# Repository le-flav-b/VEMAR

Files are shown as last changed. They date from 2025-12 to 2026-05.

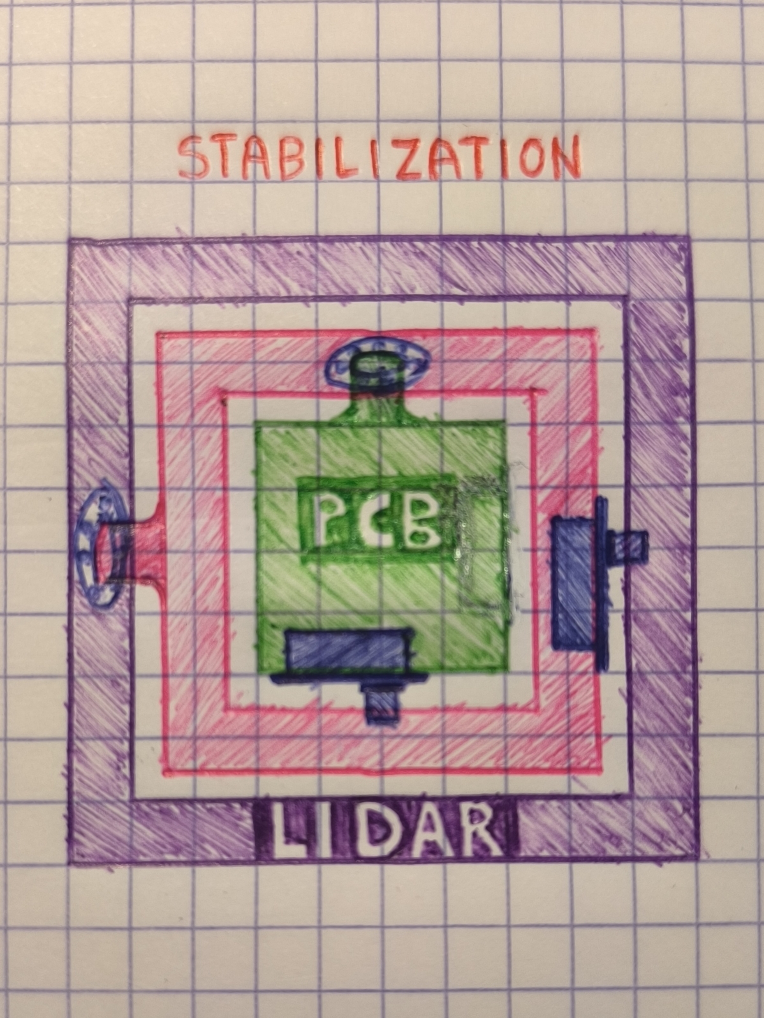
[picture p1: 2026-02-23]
mechanical/assets/lidar_schema_stabilization_concept.jpg

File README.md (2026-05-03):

Technical Documentation: Project VEMAR
======================================
Vehicle for Exploration, Mapping & Air-quality Reconnaissance
-------------------------------------------------------------

**VEMAR** is a modular platform designed for environmetal monitoring and spatial mapping.
By combining real-time locomotion control with a verstile *plug-and-play* sensor architecture, VEMAR provides a comprehensive solution for atmospheric analysis in diverse environments.

## System Overview

The VEMAR system consists of three primary layers:
* A remote controlled vehicle
* Modular Sensors
* Remote Controller

The architecture is designed for high adaptability, allowing users to reconfigure the hardware loadout without complex software recalibration.

### Mobile Platform
* Locomotion: Multi-directional drive system.
* Storage: Integrated SD card slot for localized data logging (JSON format)
* Connectivity: Real-time telemetry link between the vehicle and the handheld controller.

### Modular Sensor Suite
The system utilizes a unified interface that allows the controller to automatically detect and initialize snensors upon connection.

| Sensor ID | Sensor Category | Parameters Measured |
|:---:|:---:|:---:|
| 1 | Atmospheric | Temperature, Humidity, Barometric Pressure, PM2.5, PM10 |
| 2 | Gas Analysis | O2, CO2, CO, NH3, NO2 |
| 3 | Mapping | LiDAR (Light Detection and Ranging) for 2D spatial modeling |
| 4 | Radiation | Ionizing radiation levels (Geiger-Müller detection) |

## Functional Capabilities

### Remote Control

The end-user manages the vehicle's navigation via a dedicated controller.
The control link facilites:
* Manual Drive: Real-time steering.
* Data Visualization: A live feedback loop where sensor readings are streamed directly to the controller's display.

### Plug-and-Play Architecture

VEMAR eliminates the need for manual firmware updates when switching hardware.
* Auto-Detection: When a sensor module is attached, the controller identifies the hardware ID and adjusts the UI to display the relevant metrics.
* Hot-Swapping: Sensors can be exchanged in the field to pivot from air-quality monitoring to radiation detection or mapping.

### Data Management

The system supports dual-stream data handling:
* Live Monitoring: Immediate visaul feedback on the controller screen for rapid assessment.
* Archival Recording: On-demand recording to an onboard **SD Card**. this ensures high-fidelity data retention for post-mission analysis and mapping reconstruction.

> Caution: Removing the SD card before stopping the recording may result data corruption of the sd card.
It is recommended to wait at least 5 seconds after disabling saving before safely removing the SD card.

## Operation Workflow

1. Initialization: Power on the vehicle and controller.
2. Module Integration: Plug in desired sensor modules.
3. Verification: Cycle through sensor module readings by pressing the 'A' button on the controller.
4. Deployment: Navigate VEMAR into the target zone while monitoring live data.
5. Logging: Toggle the `Record` function to save data to the SD card by pressing 'B'.
6. Recovery: Disable data logging and retrieve the SD card for data processing.

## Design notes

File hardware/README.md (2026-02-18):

explain the folder + show what can be found where

NEED TO CLEAN UP LIBS, some are not used, and architecture is strange
check component one by one and make agreement (e.g : there is 4pin_quartz in differents libs and the symbol don't even look the same)

and also COMPLETE SYMBOLS with datasheet, footprint, ...

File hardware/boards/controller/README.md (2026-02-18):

description of the board, maybe advice or intructions

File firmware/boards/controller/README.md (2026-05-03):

# VEMAR Controller

This directory contains the core source code for the __VEMAR Controller__.

## Prerequisites

### Library Dependencies
Before compiling, ensure the __atmega328p__ library is present in the local environment: [${vemar}/firmware/libraries](../../libraries/atmega328p/).

### Hardware Requirements
* Controller PCB
* FTDI Adapter
* USB Cable

## Getting Started

### Hardware Connection
Connect the FTDI module pins to the corresponding headers on the controller
(DTR, RXD, TXD, VCC, CTS, GND) in that order from left to right.
Then plug the FTDI module into your computer via USB.

### Compilation & Flashing
Navigate to the controller directory and use the provided [Makefile](Makefile) to build and upload the firmware.

```sh
# Navigate to the controller directory
cd <path to controller firmware>

# Compile and upload
make
```

If the command fails, ensure you have the `avr-gcc` toolchain installed and that you have permissions to access the USB port.

## Technical Reference

The VEMAR Controller is the primary interface for the vehicle operation and senor data visualization.
This section outlines the hardware layout, display interface, and operational precedures.

### Hardware Layout

```
                               ANT (Antenna)
                               \|/   PWR (Power)
                   LED   LP     |    ||
   +------------------0-0------+++---++---------------------------+
  /             +-------------------------------------+            \
 /              |                                     |             \
/               |                                     |      * *     \
|       +---+   |                                     |    *  A  *   |
|       |   |   |             TFT Display             |      * *     |
|       | T |   |                                     |              |
|       |   |   |                                     |      * *     |
|       +---+   |                                     |    *  B  *   |
|               +-------------------------------------+      * *     |
|                                                                    |
|       *  *         +---------------------------+         *  *      |
|    *        *      |          POT              |      *        *   |
|   *          *     +---------------------------+     *          *  |
|   *    Jl    *                                       *    Jr    *  |
|    *        *  ___________________++++++____________  *        *   |
|       *  *    /                   ||||||            \    *  *      |
\______________/                     FTDI              \_____________/
```

### Component Descriptions

| ID | Component | Function |
|:---:|:---:|:---:|
| ANT | Antenna | Bi-directional antenna for RF communication. |
| PWR | Power Switch  | Hard-switch for system power (ON/Off). |
| LP | Power LED | Solid Red light indicates the system is powered. |
| LED | User LED | Programmable status LED (software-defined). |
| T | Toggle Switch | 3-Position switch for communication mode selection.  |
| A / B | Input Buttons | Digital inputs for UI navigation and triggers |
| POT | Slider | Linear potentiometer for auxiliary analog control. |
| Jl / Jr | Joysticks | Dual-axis analog sticks for vehicle movement. |
| FTDI | Serial Port | 6-pin interface for firmware flashing and debugging. |

### Display Interface

The onboard TFT screen provides real-time telemetry and hardware diagnostics.

```
+------------------------------+
| [MODULE]                [ID] | <-- Active Module & Available module IDs
|------------------------------|
|                              |
|        TELEMETRY DATA        | <-- Module-specific information
|                              |
|------------------------------|
| [signal]             [Rx/Tx] | <-- Signal Strength & Communication Status
+------------------------------+
```

* Module ID List: Displays IDs of all discovered modules:
    - 1: Atmospheric
    - 2: Gas
    - 3: LiDAR
    - 4: Geiger Counter
* Signal Strength: Visualized from `0` (Disconnected) to `4` (Maximum Strength).
* Communication Mode:
    - Tx: Transmitting commands to vehicle.
    - Rx: Receiving telemetry from sensors.
    - Rx/Tx: Full-duplex bi-directional communication

### Operating Instructions

Toggle the __Power Switch (PWR)__ to the `ON` position. Ensure the __Power LED (LP)__ illuminates.

The __Toggle Switch (T)__ defines the radio behavior.
> *Note*: Telemetry requiers an active Rx link.

| Position | Mode | Description |
|:---:|:---:|:---:|
| Up | Tx Only | Drive vehicle; no sensor data received. |
| Middle | Rx/Tx | Full control and real-time telemetry. |
| Down | Rx Only | Monitor sensors; vehicle control disabled. |

Movement of the vehicle is controlled via the __Left Joystick (Jl)__ and __Right Joystick (Jr)__.
> *Note*: The controller must be in __Tx__ or __Rx/Tx__ mode for movement commands to be precessed by the vehicle.

If multiple sensor modules are detected, press __Button A__ to cycle through the available data screens.
> *Note*: Telemetry updates on-screen only when the controller is in a mode that supports __Rx__.

__Button B__ and the __Slider (POT)__ are currently reserved for future firmware implementations.

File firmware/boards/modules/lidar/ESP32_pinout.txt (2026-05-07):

		 ______________
		|			   |
	  1 |3V3		VIN| 16	   -
	  2 |GND		GND| 17	   -
	  3 |D15		D13| 18
-	  4 |D2			D12| 19
-	  5 |D4			D14| 20
-	  6 |D16		D27| 21
	  7 |D17		D26| 22	   -
	  8 |D5			D25| 23	   -
	  9 |D18		D33| 24
	 10 |D19		D32| 25
-	 11 |D21		D35| 26
	 12 |RX0		D34| 27
	 13 |TX0		 VN| 28
-	 14 |D22		 VP| 29
	 15 |D23		 EN| 30
		|______________|

1	:	
2	:	
3	:	
4	:	Lidar EN
5	:	Lidar PWM
6	:	Lidar RX
7	:	
8	:	
9	:	
10	:	
11	:	SDA
12	:	
13	:	
14	:	SCL
15	:	
16	:	5V
17	:	GND
18	:	
19	:	
20	:	
21	:	
22	:	Servo B
23	:	Servo A
24	:	
25	:	
26	:	
27	:	
28	:	
29	:	
30	:

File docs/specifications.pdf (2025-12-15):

## Electronic Project

Flavien Bouleau
Benjamin Thomas
Christian Hugon

# VEMAR 🪖

## Vehicle for Exploration, Mapping & Air-quality Recon

# Overview

VEMAR is a radio-controlled modular reconnaissance vehicle. It’s used to conduct recon in places such as caves, mines or collapsed buildings in order to assess the environment before sending in real people.

The system can be configured with a terrain-adapted vehicle chassis, mapping and/or vision sensors, and modules for specific air-quality measurements. Users are able to attach different modules without needing to reprogram the vehicle.

As the user drives the vehicle, sensor data is stored on the removable SD card and displayed on the screen of the controller, allowing safe and easy recon.

# Table of Contents

# Features

## Remote Controlled Vehicle

❖ Battery powered vehicle and remote

❖ A screen on the remote to display the data from vehicle sensors

❖ Vehicle options:

- 4WD Remote controlled car with sensor slots.
- Potential to add drones, boats or other vehicle options depending on the terrain

## Modular Sensors

❖ Plug-and-play sensor modules that can be swapped out on the main board without needing to reprogram the vehicle
❖ Available sensor modules:
- Lidar: 360° mapping
- Atmosphere: particulate matter, temperature, humidity and atmospheric pressure
- Gases: CO₂, O₂, NH3

, NO₂

- Ionizing radiation (geiger) sensor

❖ Sensor data stored in onboard micro SD

# Functional Schema

## Modules Interactions

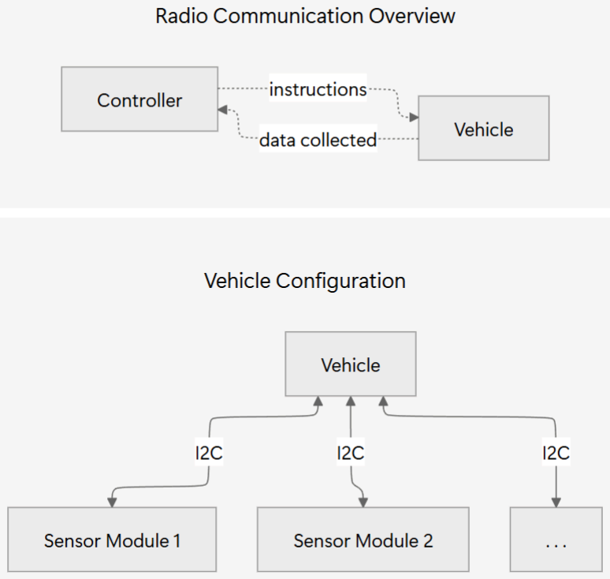
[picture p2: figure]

## Controller

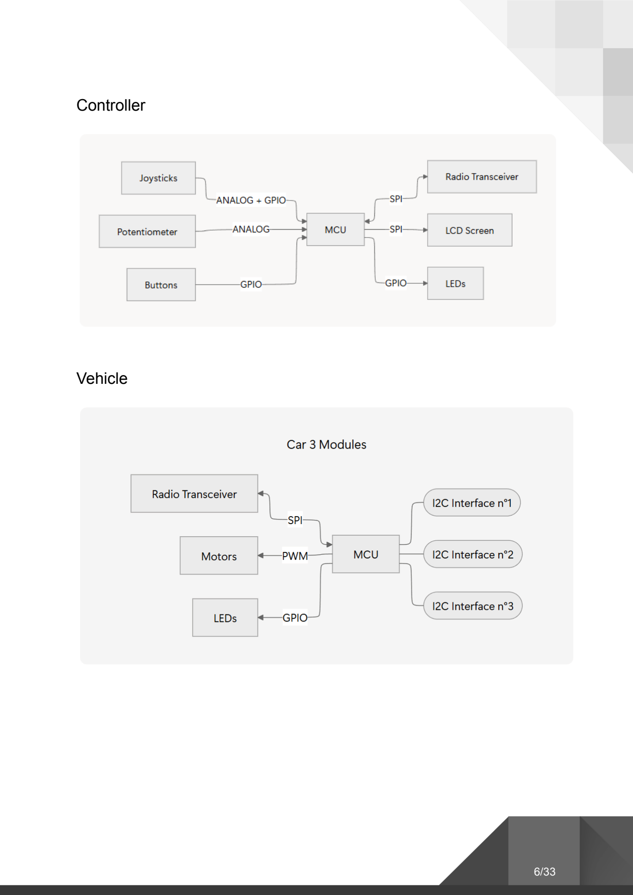
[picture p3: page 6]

## Vehicle

## Sensors Modules

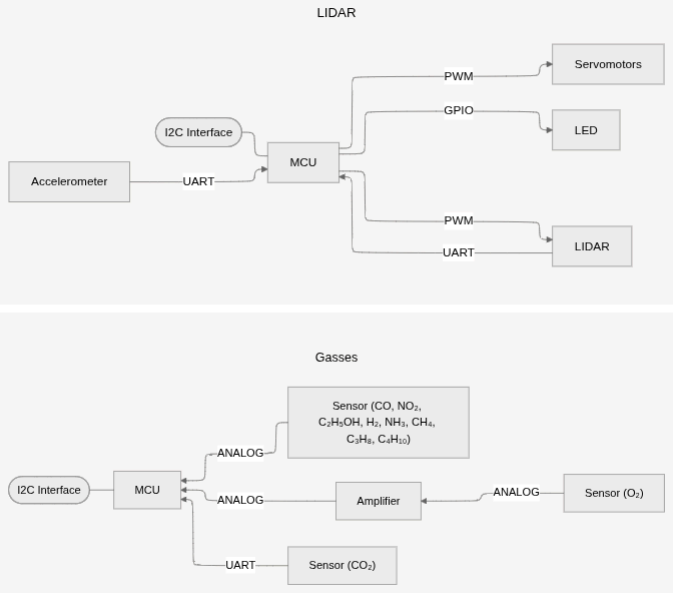
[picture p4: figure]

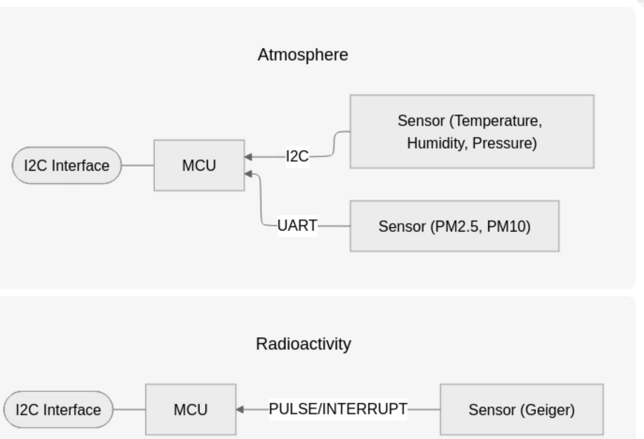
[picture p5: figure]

# User Guide

## Getting started

The user needs to choose a configuration adapted to his needs, then connect and lock all the sensor modules to the vehicle. The latter can also work without any modules.

For data collection, the user can insert a SD card into the slot.

To start VEMAR, put batteries in the vehicle and the controller and turn them on. A light signal will indicate when both devices are turned on and communication is established.

## Controlling the vehicle

❖ RC Car:
- Pushing the joysticks forward and backwards will make the car drive forwards and reverse.
- Turning the joysticks to the left or right will make the car turn likewise.

The data received from the sensors is displayed in real time on the screen of the controller.

## Exporting data

Once the vehicle is turned off the user is able to remove the SD card and upload the sensor readings to their devices for analysis.

# Protocols / Communication

## Pulse / Interrupt

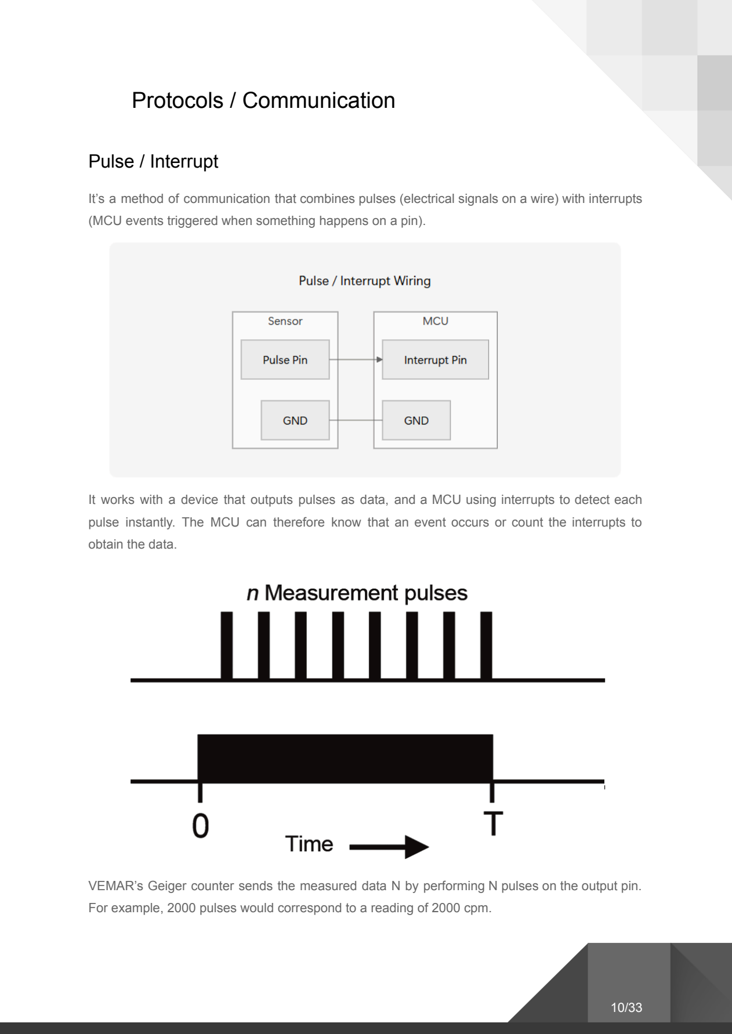
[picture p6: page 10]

It’s a method of communication that combines pulses (electrical signals on a wire) with interrupts (MCU events triggered when something happens on a pin).

It works with a device that outputs pulses as data, and a MCU using interrupts to detect each pulse instantly. The MCU can therefore know that an event occurs or count the interrupts to obtain the data.

VEMAR’s Geiger counter sends the measured data N by performing N pulses on the output pin. For example, 2000 pulses would correspond to a reading of 2000 cpm.

## PWM

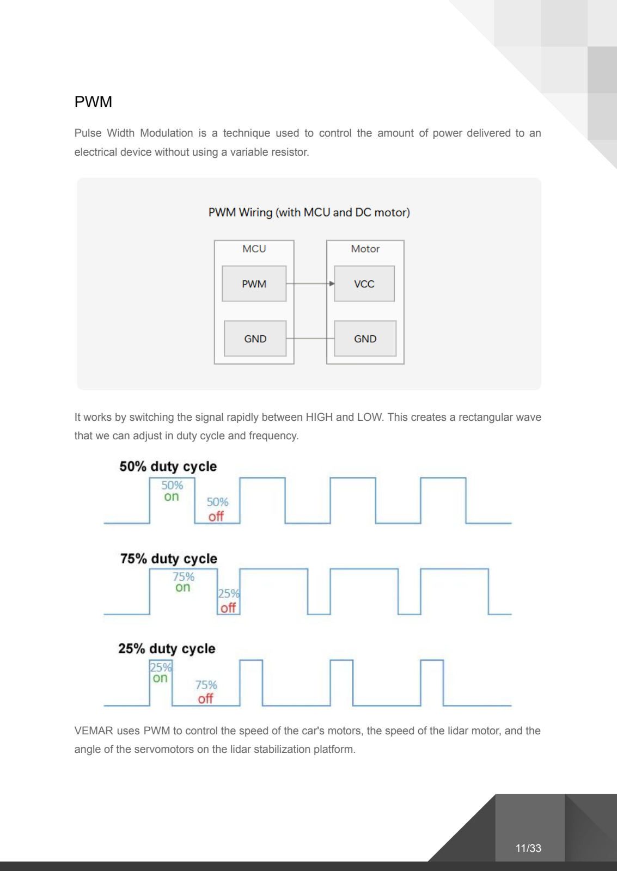
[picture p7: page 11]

Pulse Width Modulation is a technique used to control the amount of power delivered to an electrical device without using a variable resistor.

It works by switching the signal rapidly between HIGH and LOW. This creates a rectangular wave that we can adjust in duty cycle and frequency.

VEMAR uses PWM to control the speed of the car's motors, the speed of the lidar motor, and the angle of the servomotors on the lidar stabilization platform.

## Analog

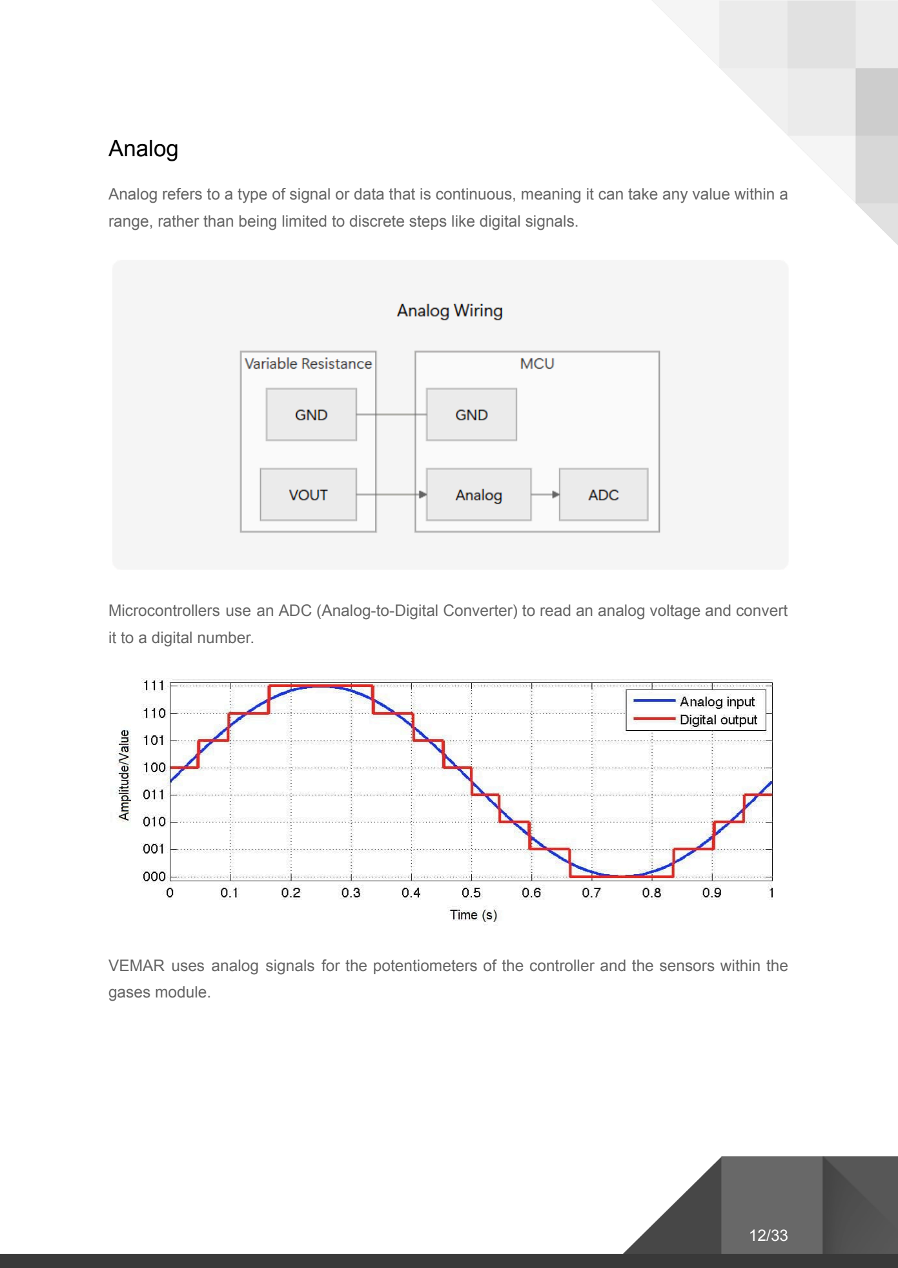
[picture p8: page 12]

Analog refers to a type of signal or data that is continuous, meaning it can take any value within a range, rather than being limited to discrete steps like digital signals.

Microcontrollers use an ADC (Analog-to-Digital Converter) to read an analog voltage and convert it to a digital number.

VEMAR uses analog signals for the potentiometers of the controller and the sensors within the gases module.

## UART

Universal Asynchronous Receiver-Transmitter is a hardware communication protocol for serial communication between devices. It allows two devices to send and receive data bit by bit.

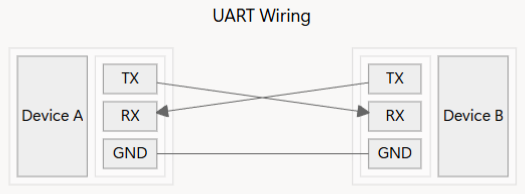
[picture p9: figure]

The transmitter and the receiver need to be configured with the same baud rate (speed), so there is no need for a clock signal. Each can send and receive data at the same time. The data is transmitted in packets composed of 1 start bit, 5 to 9 data bits, 1 optional parity bit, and 1 or 2 stop bit.

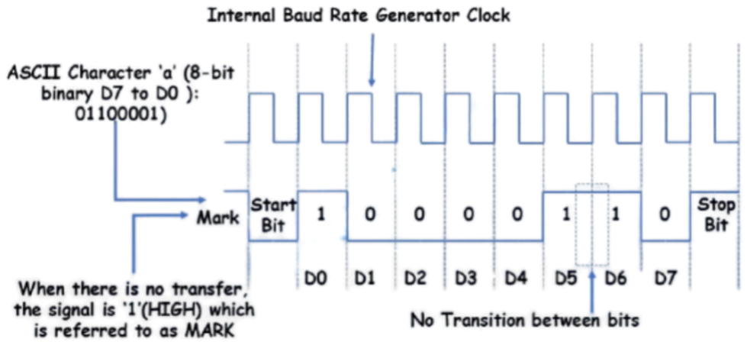
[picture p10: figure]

VEMAR uses UART to receive data from the lidar and the accelerometer of its stabilization platform, from the particulate matter sensor, and from the CO₂ sensor in the gases module.

## SPI

Serial Peripheral Interface is a synchronous serial communication protocol for short distance and high-speed communication between a master and one or more slaves.

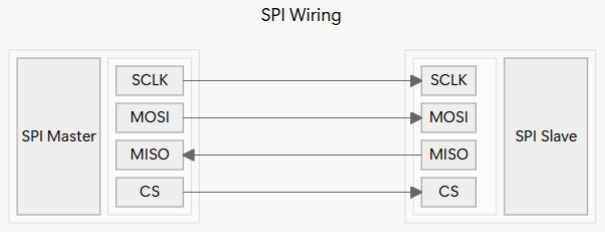
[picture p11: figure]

The master starts the communication with one or more slave devices by driving the SCLK (Serial CLocK) and CS (Chip Select) signals. Data can be sent via MOSI (Master Out Slave In) for the master and via MISO (Master In Slave Out) for the slave simultaneously.

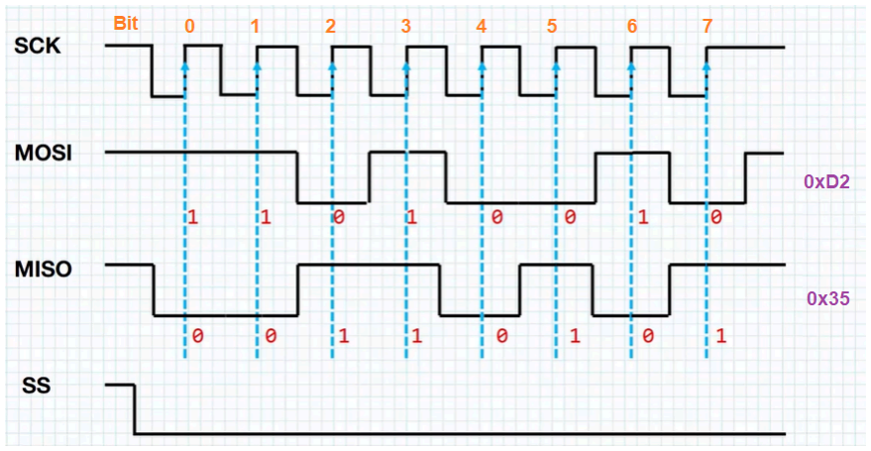
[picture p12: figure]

VEMAR uses SPI to communicate between the controller and vehicle via a radio transceiver, and control the LCD screen of the controller.

I2C

Inter-Integrated Circuit is a synchronous, serial, multi-device communications protocol for easy connection and lower speed communication between a master and one or more slaves.

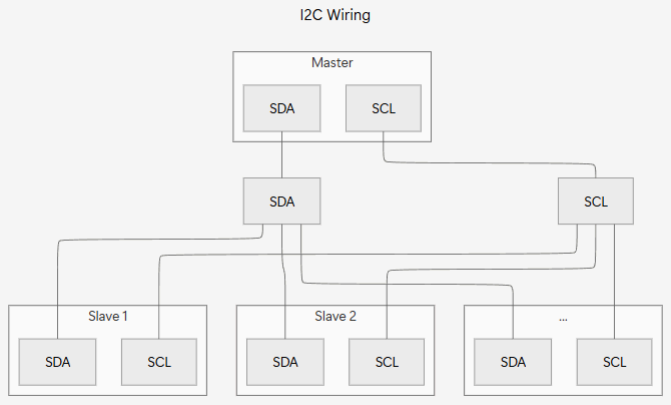
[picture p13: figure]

I2C only uses two signals, SDA (Serial DAta) and SCL (Serial CLock). It typically works in 4 steps : master sends a START condition followed by a slave address + read/write bit, addressed slave responds with ACK (acknowledge), master and slave exchange 1 or more data bytes, master sends STOP condition. Signals are interpreted according to states and changes on lines.

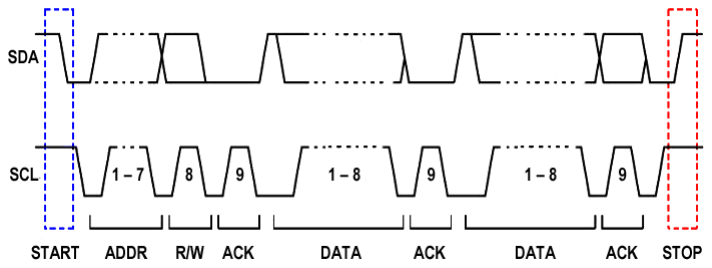
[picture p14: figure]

VEMAR uses I2C to communicate between the vehicle and all the sensor modules connected to it. It’s also used for communication within the climate sensor.

## Radio

Radio communication is a technique of sending information through electromagnetic waves that travel through the air without wires.

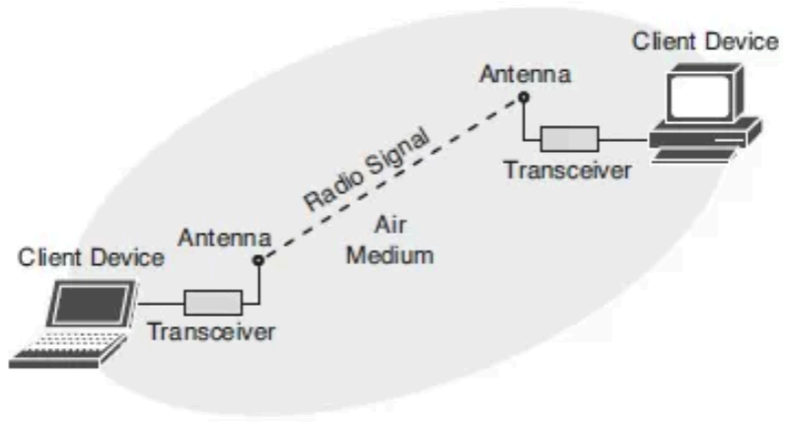
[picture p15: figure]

VEMAR uses it for the communication between the controller and the vehicle but we don’t implement it ourselves.

# Pinout

## MCU Pinout

Controller - ATmega328

MCU Pin | Name | Use
1 | PCINT19 | joystick1 digital
2 | PCINT20 | joystick2 digital
7 | XTAL1 | oscillator
8 | XTAL2 | oscillator
9 | PD5 | TFT CS
10 | PD6 | TFT RST
11 | PD7 | TFT DC
15 | MOSI | SPI: transceiver & tft
16 | MISO | SPI: transceiver & tft
17 | SCK | SPI: transceiver & tft
23 | PC0 | joystick1 analog1
24 | PC1 | joystick1 analog2
25 | PC2 | joystick2 analog1
26 | PC3 | joystick2 analog2
27 | PC4 | linear potentiometer analog
30 | PD0 | transceiver CSN
31 | PD1 | transceiver CE

Car - ATmega328

MCU Pin | Name | Use
7 | XTAL1 | oscillator
8 | XTAL2 | oscillator
9 | OC0B | PWM mosfet motor 0 CW +
10 | OC0A | PWM mosfet motor 0 CCW +
11 | PD7 | mosfet motor 0 CW -
12 | PB0 | mosfet motor 0 CCW -
13 | OC1A | PWM mosfet motor 1 CW +
14 | OC1B | PWM mosfet motor 1 CCW +
15 | MOSI | transceiver SPI
16 | MISO | transceiver SPI
17 | SCK | transceiver SPI
23 | PC0 | mosfet motor 1 CW -
24 | PC1 | mosfet motor 1 CCW -
30 | PD0 | transceiver CSN
31 | PD1 | transceiver CE

Lidar Module - ATmega128

MCU Pin | Name | Use
2 | RXD | uart rx for lidar
5 | OC3A | PWM for servomotor A
6 | OC3B | PWM for servomotor B
7 | OC3C | PWM for servomotor C
15 | OC1A | PWM for lidar
21 | VCC | power in
22 | GND | power in
23 | XTAL2 | crystal
24 | XTAL1 | crystal
25 | SCL | I2C interface for vehicle and accelerometer
26 | SDA | I2C interface for vehicle and accelerometer
27 | INT2 | Interrupt for accelerometer

Gases Module - ATtiny214

MCU Pin | Name | Function | Use
1 | VDD | Power in
2 | PA4 | bi-dir | O2 analog in
3 | PA5 | bi-dir | NH3 analog in
4 | PA6 | bi-dir | NO2 analog in
5 | PA7 | bi-dir | CO analog in
6 | TOSC1/PB3 | bi-dir | NC
7 | TOSC2/PB2 | bi-dir | NC
8 | PB1 | bi-dir | TX for CO2
9 | PB0 | bi-dir | RX for CO2
10 | PA0/RESET/UPDI | bi-dir | NC
11 | PA1 | bi-dir | SCL
12 | PA2 | bi-dir | SDA
13 | PA3/EXTCLK | bi-dir | NC
14 | GND | Power in

Climate Module - ATtiny412

MCU Pin | Name | Function | Use
1 | VDD | Power in
2 | PA6 | bi-directional | RX for pm2.5
3 | PA7 | bi-directional | TX for pm2.5
4 | PA1 | bi-directional | SCL
5 | PA2 | bi-directional | SDA
6 | PA0 | bi-directional | NC
7 | PA3 | bi-directional | NC
8 | GND | Ground

Geiger Module - ATtiny412

MCU Pin | Name | Function | Use
1 | VDD | Power in
2 | PA6 | bi-directional | EXINT used for geiger readings via pulse/interrupt
3 | PA7 | bi-directional | NC
4 | PA1 | bi-directional | SCL
5 | PA2 | bi-directional | SDA
6 | PA0 | bi-directional | NC
7 | PA3 | bi-directional | NC
8 | GND | Ground

## Generic Pinout

NRF24L01 (Transceiver)

Pin Number | Name | Pin Function | Description
1 | CE | Digital In | Chip Enable Activates RX or TX mode
2 | CSN | Digital In | SPI Chip Select
3 | SCK | Digital In | SPI Clock
4 | MOSI | Digital In | SPI Slave Data Input
5 | MISO | Digital Out | SPI Slave Data Output, with tri-state option
6 | IRQ | Digital Out | Maskable interrupt pin, Active low
7 | VDD | Power | Power Supply (+1.9V to +3.6V DC)
8 | VSS | Power | Ground (0V)
9 | XC2 | Analog Out | Crystal Pin 2
10 | XC1 | Analog Inp | Crystal Pin 1
11 | VDD_PA | Power Out | Power Supply Output (+1.8V) for the internal power amp.
12 | ANT1 | RF | Antenna interface 1
13 | ANT2 | RF | Antenna interface 2
14 | VSS | Power | Ground (0V)
15 | VDD | Power | Power Supply (+1.9V to +3.6V DC)
16 | IREF | Analog In | Reference current. Connect a 22kΩ resistor to ground
18 | VDD | Power | Power Supply (+1.9V to 3.6V DC)
19 | DVDD | Power Out | Internal digital supply output for de-coupling purposes.
20 | VSS | Power | Ground (0V)

L298N (Dual full-bridge driver)

Pin Number | Name | Function
1 | Sense A | Between this pin and ground is connected the sense resistor to control
| | the current of the load
2 | Out 1 | Outputs of the bridge A; the current that flows through the load
| | connected between these two pins is monitored at pin 1
3 | Out 2 | See above
4 | Vs | Supply voltage for the power output stages. Anon-inductive 100nF
| | capacitor must be connected between this pin and ground.
5 | Input 1 | TTL compatible inputs of the bridge A
6 | Enable A | TTL compatible enable input; the L state disables the bridge A (enable A)
7 | Input 2 | TTL compatible inputs of the bridge A
8 | GND | Ground
9 | Vss | Supply voltage for the logic blocks, A 100nF capacitor must be
| | connected between this pin and ground
10 | Input 3 | TTL compatible inputs of the bridge B
11 | Enable B | TTL compatible enable input: the L state disables the bridge B (enable B)
12 | Input 4 | TTL compatible inputs of the bridge B
13 | Out 3 | Outputs of the bridge B. The current that flows through the load
| | connected between these two pins is monitored at pin 15
14 | Out 4 | See above
15 | Sense B | Between this pin and ground is connected the sense resistor to control
| | the current of the load

MiCS-6814 (MOS sensor)

Pin Number | Name
A | Rs2
B | Rh1 RED, Rs1 RED
C | Rh1 NH3
D | Rs1 NH3
E | Rh2 NH3
F | Rs2 NH3
G | Rh2 RED
H | Rs2 RED
J | Rh1 OX, Rs1 OX
K | Rh2 OX

Note:

- OX: Oxidising gases
- RED: Reducing gases
- NH3: Ammonia

MH-Z1911A (CO2 sensor)

Pin | Type | Description
1 | PWM output | Not connected as we’re using UART
2 | UART TX | data out
3 | UART RX | data in
4 | Power in | +3.3V
5 | GND
6 | NC | Not Connected
7 | HD (zero point calibration) | Used for ‘0 point calibration’ (forcing the reading to 400 ppm in fresh air). Connect this pin to control calibration or leave disconnected to rely on automatic calibration.

SDS011 (Laser PM2.5 Sensor)

Pin Number | Name | Comment
1 | NC | Not Connect
2 | 1μm | PM2.5: 0-999μg/m3; PWM Output
3 | 5V | 5V Input
4 | 2.5μm | PM10: 0-999μg/m3; PWM Output
5 | GND | Ground
6 | R | RX of UART (TTL) @3.3V
7 | T | TX of UART (TTL) @3.3V

AO-03 (Oxygen Sensor)

Pin Number

Vsensor+

Vsensor-

AD8552 (amplifier for O2 Sensor)

Pin | Type | Description
OUT A | Output | Amplifier Output (analog)
IN A - | Input | Inverting input of amplifier
IN A + | Input | non-inverting input of amplifier
VSS | Ground | Ground
VDD | Power | +3.3V
OUTB | Output | Amplifier Output (analog)

YDLIDAR X2

Pin | Type | Description
VCC | Power Supply | +5V
Tx | Output | System Serial Output
GND | Power Supply | Negative
M_SCTR | Input | Motor Speed Control Terminal

Geiger Counter

Pin | Type | Description
VCC | Power Supply | +5V
INT | Output | Interrupt / Pulse
GND | Power Supply

TFT 3.2 Inch Display SPI — ILI9341

Pin Number | Name | Description
1 | VCC | Power supply is positive (3.3V~5V)
2 | GND | Power ground
3 | CS | Selection control signal
4 | RESET | Reset control signal
5 | DC/RS | Register/Data selection control signal
6 | SDI (MOSI) | SPI bus write data signal
7 | SCK | SPI bus clock signal
8 | LED | Backlight control signal (high level lighting, if you do not need control, connect to 3.3V)
9 | SDO (MISO) | SPI bus read data signal (cannot be connected if not needed)
10 | T_CLK | Touch Screen SPI bus clock pin
11 | T_CS | Touch Screen chip select control pin
12 | T_DIN | Touch Screen SPI bus write data pin
13 | T_DO | Touch Screen SPI bus read data pin
14 | T_IRQ | Touch Screen interrupt detection pin

ATmega328P

Pin | Type | Description
VCC | Power in | +3.3V or +5V
GND | Ground
PBx | bi-directional | input & output
PCx | bi-directional | input & output
PC6 / RESET | input | reset input
PDx | bi-directional | input & output
AVCC | Power in | supply voltage for a/d converter
AREF | analog reference | analog reference pin for a/d converter
ADCx | input | analog inputs

ATtiny412

Pin | Type | Description
VDD | Power Input
GND | Ground
PAx | bi-directional | GPIO with a/d
PA3/EXTCLK | bi-directional | GPIO with option to take external clock source
PA0/RESET/UPDI | bi-directional | by default it’s the dedicated debug pin (UPDI) that’s used to program the chip. It can also be configured as RESET or used as a regular GPIO

ATmega128A

S90

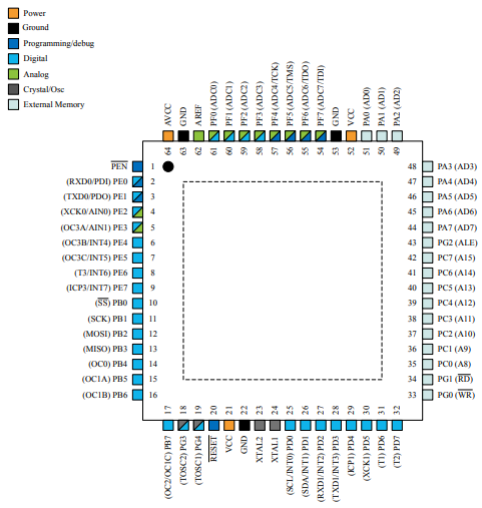
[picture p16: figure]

Pin | Type | Description
VCC | Power Supply | +5V
PWM | Input | PWM
GND | Power Supply

BN055

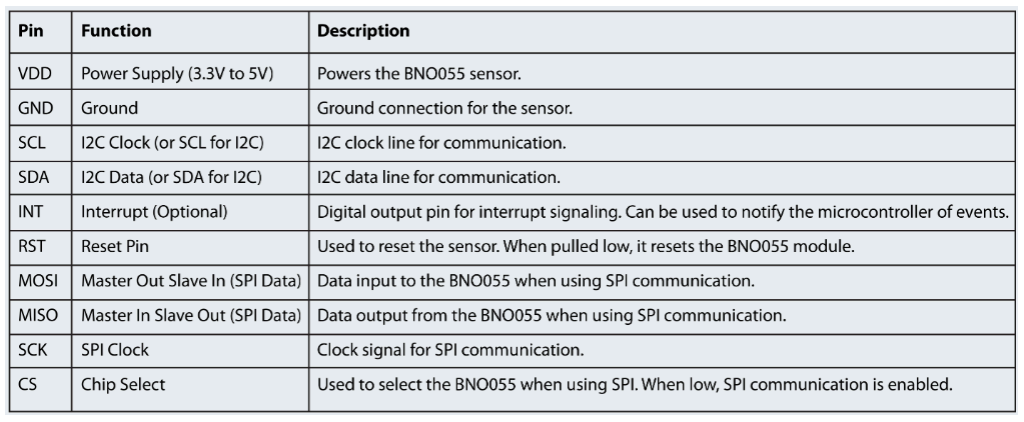
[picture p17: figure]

DC Motor

Pin | Type | Description
VCC | Power Supply | +12V
GND | Power Supply

# Power Budget

## Controller

Component | Quantity | Max Intensity (mA) | Tension (V) | Power (mW)
NRF24L01 | 1 | 12.3 | 3.3 | 36.9
TFT LCD | 1 | - | 3.3 / 5 | 720
ATmega328 | 1 | 15 | 5 | 75

## Car

Component | Quantity | Max Intensity (mA) | Tension (V) | Power (mW)
DC motor | 2 | 2000 | 12 | 48000
NRF24L01 | 1 | 12.3 | 3.3 | 36.9
ATmega328 | 1 | 15 | 5 | 75

## Sensors

Lidar Module

Component | Quantity | Max Intensity (mA) | Tension (V) | Power (mW)
ATMEGA128 | 1 | 20 | 5 | 100
YDLIDAR X2 | 1 | 380 | 5 | 1900
SG90 | 3 | 700 | 5 | 10500
BNO055 | 1 | 12 | 3.3 | 40

Climate Module:

Component | Quantity | Max Intensity (mA) | Tension (V) | Power (mW)
ATtiny412 | 1 | 6 | 5 | 30
BME280 | 1 | 0.0007 | 3.3 | 0.0023
SDS011 | 1 | 80 | 5 | 400

Geiger Module:

Component | Quantity | Max Intensity (mA) | Tension (V) | Power (mW)
ATtiny412 | 1 | 6 | 5 | 30
Geiger | 1 | 30 | 5 | 150

Gas Module:

Component | Quantity | Max Intensity (mA) | Tension (V) | Power (mW)
ATtiny214 | 4 | 6 | 5 | 30
MH-Z19 | 1 | 50 | 5 | 250
AO 03 | 1 | 10 | 3.3 | 50
AD8552M | 1 | 60 | 3.3 | 198
MiCS-6814 | 1 | 32 | 2.4 | 76.8

# Bonus

❖ Improve lidar rendering with algorithms

❖ Add automatizations

❖ Make a Geiger Counter module

❖ Include MiCS sensor for pollutants in Gases module

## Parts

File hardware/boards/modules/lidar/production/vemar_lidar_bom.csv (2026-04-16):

Designator | Footprint | Quantity | Value | LCSC Part #
C1, C10, C13, C14, C5, C6, C7, C8 | 0603 | 8 | 100nF
C11, C12, C2, C3 | 0603 | 4 | 12pF
C15 | 0603 | 1 | 1uF
C4 | 0603 | 1 | 4.7uF
C9 | CP_Elec_4x5.4 | 1 | 10uF
D1 | 0603 | 1 | GREEN
D2 | 0603 | 1 | RED
J1 | JST_XH_B5B-XH-A_1x05_P2.50mm_Vertical | 1 | JST
J2 | PinHeader_1x06_P2.54mm_Vertical | 1 | Dupont
J3 | PinHeader_1x04_P2.54mm_Vertical | 1 | Dupont
J4 | JST_XH_B4B-XH-A_1x04_P2.50mm_Vertical | 1 | JST
J5, J6 | JST_XH_B3B-XH-A_1x03_P2.50mm_Vertical | 2 | JST
Q1 | SOT-23 | 1 | AO3400A
R1, R5 | 0603 | 2 | 10K
R2, R3 | 0603 | 2 | 330
R4 | 0603 | 1 | 100
R6 | 0603 | 1 | 1K
SW1 | SW_Tactile3x2.5 | 1 | SW_Push
U1 | TQFP-64_14x14mm_P0.8mm | 1 | ATmega128A
U2 | BNO055_Hand_Soldering_LGA-28_5.2x3.8mm_P0.5mm | 1 | BNO055
Y1 | crys_osc_smd3225_4 | 1 | 16MHz
Y2 | Crystal_SMD_3215-2Pin_3.2x1.5mm | 1 | 32.768kHz

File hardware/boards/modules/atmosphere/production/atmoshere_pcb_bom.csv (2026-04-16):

Designator | Footprint | Quantity | Value | LCSC Part #
C19, C20, C21, C22, C31 | C_0603 | 5 | 100nF
D1 | LED_3mm_THT | 1 | ~
G1 | GPIO_HEADER | 1 | ~
J4 | ATtiny_Programming_Header | 1 | ~
R1 | R_0603 | 1 | 220
S3 | BME280 | 1 | BME280
S4 | SDS011 | 1 | SDS011
U7 | ATtiny1614 | 1 | ATtiny1614
U8 | SN74LVC125 | 1 | buffer

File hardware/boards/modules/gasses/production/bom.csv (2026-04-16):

Designator | Footprint | Quantity | Value | LCSC Part #
_4, _2 |  | 2
_3, | mounting_hole | 2 | mounting_hole
A1 | AD8552 | 1 | AD8552
C12 | C_0805 | 1 | 4.7uF
C13, C14, C15 | C_0603 | 3 | 10nF
C16 | C_1206 | 1 | 10uF
C18, C23, C32 | C_0603 | 3 | 100nF
D1 | LED_3mm_THT | 1 | ~
G2 | GPIO_HEADER | 1 | Module Connector
J1 | ATtiny_Programming_Header | 1 | Program Header
M1 | MiCS-6814 | 1 | MiCS-6814
O1 | AO_03 | 1 | AO-03
R1, R4 | R_0603 | 2 | 100R
R10 | R_0603 | 1 | 27R
R11 | R_0603 | 1 | 130
R12 | R_0603 | 1 | 820R
R2, R3 | R_0603 | 2 | 10K
R5 | R_0603 | 1 | 400K
R6 | R_0603 | 1 | 220
S5 | MH-Z1911A | 1 | MH-Z1911A
U6 | ATtiny1614 | 1 | ~
U9 | SN74LVC125 | 1 | Buffer

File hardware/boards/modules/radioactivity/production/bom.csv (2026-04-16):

Designator | Footprint | Quantity | Value | LCSC Part #
_3, _2, |  | 3
100R1 | SMD_3P_3.8X3.6 | 1 | Potentiometer
C10, C5, C9 | C_1206 | 3 | 10n 1000V
C12 | C_0603 | 1 | 100nF
C6 | C_0603 | 1 | 270pF
D2, D3, D4 | SMA(DO-214AC) | 3 | ES1J
D5 | LED_3mm_THT | 1 | ~
G2 | gpio_1 | 1 | TEST
J3 | Jumper_2 | 1 | jmp1
L1 | SMD(7.1x6.6) | 1 | 100uH
L2 | C_0603 | 1 | 10mH
Q1, Q3, Q4 | SOT-23 | 3 | S8050
Q2 | SOT-23 | 1 | MMBTA42
R1, R2 | R_0603 | 2 | 33k
R10, R7, R9 | R_0603 | 3 | 470K
R12, R6 | R_0603 | 2 | 10K
R13, R14, R15, R16, R17, R5 | R_0603 | 6 | 10M
R18 | R_0603 | 1 | 220
R3 | R_0603 | 1 | 3k
R4 | R_0603 | 1 | 100k
R8 | R_0603 | 1 | 47K
S1 | buzzer_8.5x8.5 | 1 | Speaker
T1 | SOT353 | 1 | 74LVC1G17GW
U1, U2 | SOIC-8 | 2 | TLC555
U3 | ATtiny1614 | 1 | ATTINY1614

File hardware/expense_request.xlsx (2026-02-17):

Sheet: Feuil1
 |  | Date : | 2026/00/00
 |  | Pôle : | 42 Chips
 |  | Responsable : | Robin K.
 |  | DEMANDE DE DEPENSE
 | Fournisseur | TTC | Commentaires | Validation 42
1 | AliExpress | 21.38 € | Equipements Labelec
2 | LCSC | 59.01 € | Equipements Labelec
3 | Mouser | 7.12 € | Equipements Labelec
4
5
6
7
8
9
10
11
12
13
14
15
16
17
18
19
20
 |  | 87.51 €

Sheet: AliExpress
Commentaire | Fournisseur | RefFournisseur | PrixUnitaire (TTC) | Quantitée | PrixTotal (TTC)
10Pcs SMA Female Jack Male Plug Adapter | AliExpress (https://fr.aliexpress.com/?spm=a2g0o.home.logo.1.864f7065nsY5sf) | No 7 X 10PCS (https://fr.aliexpress.com/item/1005003176364619.html) | 3.21 | 1 | 3.21 €
2.4G Wifi Antenna 3dBi Foldable | AliExpress (https://fr.aliexpress.com/?spm=a2g0o.home.logo.1.864f7065nsY5sf) | 2.4g antenna x1 (https://fr.aliexpress.com/item/1005006814234708.html?scm_id=1007.40050.354490.0&scm-url=1007.40050.354490.0) | 0.44 | 2 | 0.88 €
3.2 inch TFT LCD display No Touch Module ILI9341 | AliExpress (https://fr.aliexpress.com/?spm=a2g0o.home.logo.1.864f7065nsY5sf) | TN 3.2 No Touch (https://fr.aliexpress.com/item/1005007333267197.html) | 9.19 | 1 | 9.19 €
Replacement Hall effect Joystick 3D Analog Sensor ThumbStick | AliExpress (https://fr.aliexpress.com/?spm=a2g0o.home.logo.1.864f7065nsY5sf) | For PS4 2PCS (https://fr.aliexpress.com/item/1005008600410715.html) | 2.47 | 1 | 2.47 €
10Pcs MTS-103 DPDT ON-OFF-ON Toggle Switch | AliExpress (https://fr.aliexpress.com/?spm=a2g0o.home.logo.1.864f7065nsY5sf) | MTS103 Dark Blue (https://fr.aliexpress.com/item/1005008776985434.html) | 3.49 | 1 | 3.49 €
 |  |  |  |  | 0.00 €
Livraison et expédition |  |  | 2.14 | 1 | 2.14 €
 |  |  |  | Total (TTC) | 21.38 €

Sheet: LCSC
Commentaire | Fournisseur | RefFournisseur | PrixUnitaire (TTC) | Quantitée | PrixTotal (TTC)
AVR 8 Bit 20MHz 23 TQFP-32(7x7) Microcontrollers RoHS | LCSC (https://www.lcsc.com/) | C14877 (https://www.lcsc.com/product-detail/C14877.html?s_z=n_ATmega328P) | 1.7187 | 1 | 1.72 €
YXC Crystal Oscillators X322516MLB4SI | LCSC (https://www.lcsc.com/) | C13738 (https://www.lcsc.com/product-detail/C13738.html?s_z=n_crystal%252016mhz) | 0.059 | 10 | 0.59 €
NORDIC NRF24L01P-R (Transceiver) | LCSC (https://www.lcsc.com/) | C8791 (https://www.lcsc.com/product-detail/C8791.html?s_z=n_nRF24L01) | 2.0451 | 2 | 4.09 €
SKYWORKS RFX2401C (RF Front End) | LCSC (https://www.lcsc.com/) | C19213 (https://www.lcsc.com/product-detail/C19213.html?s_z=n_RFX2401C) | 0.7744 | 2 | 1.55 €
UMW AMS1117-3.3 (LDO) | LCSC (https://www.lcsc.com/) | C347222 (https://www.lcsc.com/product-detail/C347222.html?s_z=n_ams1117) | 0.0315 | 10 | 0.32 €
UMW AMS1117-5.0 (LDO) | LCSC (https://www.lcsc.com/) | C347223 (https://www.lcsc.com/product-detail/C347223.html?s_z=n_ams1117) | 0.0315 | 10 | 0.32 €
hanxia HX-B3U-1000P-1.6N (Tactile Switch) | LCSC (https://www.lcsc.com/) | C49234121 (https://www.lcsc.com/product-detail/C49234121.html?s_z=n_b3u1000p) | 0.082 | 10 | 0.82 €
Yuandi TS-1094TS-B3D2-T-Y (Tactile Switch) | LCSC (https://www.lcsc.com/) | C19077684 (https://www.lcsc.com/product-detail/C19077684.html?s_z=n_switch%2520push%252012mm) | 0.1058 | 5 | 0.53 €
Khon SC203AD1 (Switch Cap) | LCSC (https://www.lcsc.com/) | C42435492 (https://www.lcsc.com/product-detail/C42435492.html?s_z=s_Switches%257CAccessories) | 0.0193 | 20 | 0.39 €
SHOU HAN MST-12D18G4 SPDT Slide Switch | LCSC (https://www.lcsc.com/) | C49023767 (https://www.lcsc.com/product-detail/C49023767.html?s_z=n_spdt) | 0.0675 | 5 | 0.34 €
YONGYUTAI 1N4007 (Diode) | LCSC (https://www.lcsc.com/) | C2892681 (https://www.lcsc.com/product-detail/C2892681.html?s_z=n_1n4007%2520sod123) | 0.004 | 50 | 0.20 €
ROQANG RVT1V101M0605 (Capacitor 100uF) | LCSC (https://www.lcsc.com/) | C3151830 (https://www.lcsc.com/product-detail/C3151830.html) | 0.0393 | 10 | 0.39 €
ROQANG RVT1H220M0605 (Capacitor 22uF) | LCSC (https://www.lcsc.com/) | C72505 (https://www.lcsc.com/product-detail/C72505.html) | 0.0283 | 20 | 0.57 €
Samsung Electro-Mechanics CL31B106KBHNNNE (Capacitor 10 uF) | LCSC (https://www.lcsc.com/) | C89632 (https://www.lcsc.com/product-detail/C89632.html) | 0.0479 | 10 | 0.48 €
muRata GRM21BZ71H475KE15L (Capacitor 4.7 uF) | LCSC (https://www.lcsc.com/) | C437557 (https://www.lcsc.com/product-detail/C437557.html) | 0.0791 | 5 | 0.40 €
Samsung Electro-Mechanics CL10A105KP8NNNC (Capacitor 1uF) | LCSC (https://www.lcsc.com/) | C26413 (https://www.lcsc.com/product-detail/C26413.html?s_z=n_capacitor%25201uf%25200603) | 0.0048 | 10 | 0.05 €
YAGEO CC0603KRX7R9BB104 (Capacitor 100nF) | LCSC (https://www.lcsc.com/) | C14663 (https://www.lcsc.com/product-detail/C14663.html?s_z=n_capacitor%25200603) | 0.0019 | 100 | 0.19 €
KEMET C0603C333K4RAC7867 (Capacitor 33nF) | LCSC (https://www.lcsc.com/) | C599735 (https://www.lcsc.com/product-detail/C599735.html?s_z=n_capacitor%252033nf%25200603) | 0.0119 | 10 | 0.12 €
Samsung Electro-Mechanics CL10B103KB8NNNC (Capacitor 10 nF) | LCSC (https://www.lcsc.com/) | C1589 (https://www.lcsc.com/product-detail/C1589.html?s_z=n_capacitor%252010nf%25200603) | 0.0031 | 50 | 0.15 €
Samsung Electro-Mechanics CL10B472KB8NNNC (Capacitor 4.7nF) | LCSC (https://www.lcsc.com/) | C1621 (https://www.lcsc.com/product-detail/C1621.html?s_z=n_capacitor%25204.7nf%25200603) | 0.0043 | 50 | 0.21 €
Samsung Electro-Mechanics CL10C222JB8NNNC (Capacitor 2.2nF) | LCSC (https://www.lcsc.com/) | C33353 (https://www.lcsc.com/product-detail/C33353.html?s_z=n_capacitor%25202.2nf%25200603) | 0.0093 | 20 | 0.19 €
Samsung Electro-Mechanics CL10C222JB8NNNC (Capacitor 1nF) | LCSC (https://www.lcsc.com/) | C1588 (https://www.lcsc.com/product-detail/C1588.html?s_z=n_capacitor%25200603%25201nf) | 0.0027 | 50 | 0.14 €
YAGEO CC0603KRX7R9BB221 (Capacitor 220pF) | LCSC (https://www.lcsc.com/) | C107081 (https://www.lcsc.com/product-detail/C107081.html?s_z=n_capacitor%25200603%2520220pf) | 0.0026 | 100 | 0.26 €
YAGEO CC0603JRNPO9BN120 (Capacitor 12pF) | LCSC (https://www.lcsc.com/) | C107034 (https://www.lcsc.com/product-detail/C107034.html?s_z=n_capacitor%25200603%252012pf) | 0.0027 | 100 | 0.27 €
CCTC TCC0603COG1R5C500CT (Capacitor 1.5pF) | LCSC (https://www.lcsc.com/) | C376772 (https://www.lcsc.com/product-detail/C376772.html?s_z=n_capacitor%25200603%25201.5pf) | 0.0023 | 100 | 0.23 €
FOJAN FCC0603N1R0C500CT (1pF) | LCSC (https://www.lcsc.com/) | C5137611 (https://www.lcsc.com/product-detail/C5137611.html?s_z=n_capacitor%2520smd%25200603%25201pf) | 0.0023 | 100 | 0.23 €
CCTC TCC0603COG0R3B500CT (Capacitor 0.3pF) | LCSC (https://www.lcsc.com/) | C5375816 (https://www.lcsc.com/product-detail/C5375816.html?s_z=n_capacitor%25200603%25200.3pf) | 0.0036 | 100 | 0.36 €
YAGEO PA0603FRP070R001L (Resistor 1MΩ) | LCSC (https://www.lcsc.com/) | C6949223 (https://www.lcsc.com/product-detail/C6949223.html?s_z=n_resistor%2520smd%25201m%25200603) | 0.1507 | 5 | 0.75 €
FOJAN FRC0603J223 TS (Resistor 22kΩ) | LCSC (https://www.lcsc.com/) | C2907128 (https://www.lcsc.com/product-detail/C2907128.html?s_z=n_resistor%2520smd%25200603%252022k) | 0.0008 | 100 | 0.08 €
FOJAN FRC0603J203 TS (Resistor 20kΩ) | LCSC (https://www.lcsc.com/) | C2907124 (https://www.lcsc.com/product-detail/C2907124.html?s_z=n_resistor%2520smd%25200603%252020k) | 0.0007 | 100 | 0.07 €
FOJAN FRC0603F1002TS (Resistor 10kΩ) | LCSC (https://www.lcsc.com/) | C2906982 (https://www.lcsc.com/product-detail/C2906982.html?s_z=n_resistor%25200603%252010k) | 0.0008 | 100 | 0.08 €
FOJAN FRC0603F2001TS (Resistor 2kΩ) | LCSC (https://www.lcsc.com/) | C2907022 (https://www.lcsc.com/product-detail/C2907022.html?s_z=n_resistor%25200603%25202k) | 0.0009 | 100 | 0.09 €
FOJAN FRC0603J102 TS (Resistor 1kΩ) | LCSC (https://www.lcsc.com/) | C2907113 (https://www.lcsc.com/product-detail/C2907113.html?s_z=n_resistor%25200603%25201k) | 0.0007 | 100 | 0.07 €
FOJAN FRC0603J331 TS (Resistor 330) | LCSC (https://www.lcsc.com/) | C2907152 (https://www.lcsc.com/product-detail/C2907152.html?s_z=n_resistor%25200603%2520330Ohm) | 0.0008 | 100 | 0.08 €
BOURNS PTA4543-2015DPB103 (Slide Potentiometer) | LCSC (https://www.lcsc.com/) | C17444183 (https://www.lcsc.com/product-detail/C17444183.html) | 1.3326 | 1 | 1.33 €
XRRH8D43-100M (Inductor 10uH) | LCSC (https://www.lcsc.com/) | C5351469 (https://www.lcsc.com/product-detail/C5351469.html) | 0.1051 | 5 | 0.53 €
Sunltech SCC1608C8N2JSP (Inductor 8.2nH) | LCSC (https://www.lcsc.com/) | C412032 (https://www.lcsc.com/product-detail/C412032.html) | 0.0102 | 50 | 0.51 €
HYHONGYEX HBLS1608-3N9S (Inductor 3.9nH) | LCSC (https://www.lcsc.com/) | C964023 (https://www.lcsc.com/product-detail/C964023.html?s_z=n_inductor%25200603%25203.9nh) | 0.008 | 50 | 0.40 €
Chilisin BSCH001608082N7S00 (Inductor 2.7nH) | LCSC (https://www.lcsc.com/) | C5252358 (https://www.lcsc.com/product-detail/C5252358.html?s_z=n_inductor%25200603%25202.7nh) | 0.0128 | 20 | 0.26 €
FH VHF160808H2N4ST (Inductor 2.4nH) | LCSC (https://www.lcsc.com/) | C395082 (https://www.lcsc.com/product-detail/C395082.html?s_z=n_inductor%25200603%25202.4nh) | 0.006 | 100 | 0.60 €
muRata LQW18AN2N4C80D (Inductor 2.4nH) | LCSC (https://www.lcsc.com/) | C173290 (https://www.lcsc.com/product-detail/C173290.html?s_z=n_inductor%25200603%25202.4nh) | 0.1037 | 5 | 0.52 €
YONGYUTAI YLED0603R (LED Red) | LCSC (https://www.lcsc.com/) | C19171390 (https://www.lcsc.com/product-detail/C19171390.html?s_z=n_led%2520smd%25200603) | 0.0051 | 100 | 0.51 €
YONGYUTAI YLED0603G (LED Green) | LCSC (https://www.lcsc.com/) | C19273151 (https://www.lcsc.com/product-detail/C19273151.html?s_z=n_led%2520smd%25200603) | 0.0049 | 100 | 0.49 €
Micro SD card (TF card) | LCSC (https://www.lcsc.com/) | C428492 (https://www.lcsc.com/product-detail/C428492.html) | 0.8667 | 1 | 0.87 €
YXC Crystal Oscillators X32258MOB4SI | LCSC | C2682775 (https://www.lcsc.com/product-detail/C2682775.html) | 0.1583 | 5 | 0.79 €
YXC Crystal Oscillators XKXGI-SUA-32.768K | LCSC | C5213671 (https://www.lcsc.com/product-detail/C5213671.html) | 0.1619 | 5 | 0.81 €
FOSAN SS36 | LCSC | C3014012 (https://www.lcsc.com/product-detail/C3014012.html) | 0.0259 | 20 | 0.52 €
TI TPS54302DDCR buck converter | LCSC | C311983 (https://www.lcsc.com/product-detail/C311983.html) | 0.1517 | 5 | 0.76 €
Rubycon 35YXJ470M10x16 (capacitor alu 470uF) | LCSC | C88732 (https://www.lcsc.com/product-detail/C88732.html) | 0.164 | 5 | 0.82 €
Rubycon 50YXF10MEFC5X11 (capacitor alu 10uF) | LCSC | C88726 (https://www.lcsc.com/product-detail/C88726.html) | 0.0475 | 10 | 0.47 €
Rubycon 50YXF22MEFC5X11 (capacitor alu 22uF) | LCSC | C88755 (https://www.lcsc.com/product-detail/C88755.html) | 0.0474 | 10 | 0.47 €
CL10A226MO7JZNC (Capacitor 22uF) | LCSC | C2762594 (https://www.lcsc.com/product-detail/C2762594.html) | 0.0452 | 5 | 0.23 €
MOSFET N-CH AO3400A | LCSC | C20917 (https://www.lcsc.com/product-detail/C20917.html) | 0.0791 | 5 | 0.40 €
MOSFET P-CH FQP27P06 | LCSC | C7503194 (https://www.lcsc.com/product-detail/C7503194.html) | 0.3366 | 5 | 1.68 €
Bipolar Transistor NPN 2N3904X | LCSC | C5156722 (https://www.lcsc.com/product-detail/C5156722.html) | 0.0391 | 10 | 0.39 €
MOSFET P-CH AO3401A | LCSC | C15127 (https://www.lcsc.com/product-detail/C15127.html) | 0.0583 | 10 | 0.58 €
MICROCHIP ATMEGA128A-AU | LCSC | C6510 (https://www.lcsc.com/product-detail/C6510.html) | 4.1735 | 1 | 4.17 €
MICROCHIP ATMEGA328P-AU | LCSC | C14877 (https://www.lcsc.com/product-detail/C14877.html) | 1.9841 | 1 | 1.98 €
Bosch BNO055 accelerometer | LCSC | C93216 (https://www.lcsc.com/product-detail/C93216.html) | 9.3482 | 1 | 9.35 €
CL10A106MA8NRNC (Capacitor 10uF) | LCSC | C96446 (https://www.lcsc.com/product-detail/C96446.html) | 0.0182 | 20 | 0.36 €
CC0603JRNPO9BN750 (Capacitor 75pF) | LCSC | C282074 (https://www.lcsc.com/product-detail/C282074.html) | 0.0032 | 100 | 0.32 €
Viking ARG03BTC5113 (Resistor 511kΩ) | LCSC | C2684557 (https://www.lcsc.com/product-detail/C2684557.html) | 0.0232 | 20 | 0.46 €
PANASONIC ERA3AEB1053V (Resistor 105kΩ) | LCSC | C491109 (https://www.lcsc.com/product-detail/C491109.html) | 0.0805 | 5 | 0.40 €
FOJAN FRC0603F4322TS (Resistor 43.2kΩ) | LCSC | C2930102 (https://www.lcsc.com/product-detail/C2930102.html) | 0.0013 | 100 | 0.13 €
FOJAN FRC0603F5761TS (Resistor 5.76kΩ) | LCSC | C2933239 (https://www.lcsc.com/product-detail/C2933239.html) | 0.0012 | 100 | 0.12 €
FOJAN FRC0603F4701TS (Resistor 4.7kΩ) | LCSC | C2907034 (https://www.lcsc.com/product-detail/C2907034.html) | 0.0011 | 100 | 0.11 €
UNI-ROYAL 0603WAJ0681T5E (Resistor 680Ω) | LCSC | C25253 (https://www.lcsc.com/product-detail/C25253.html) | 0.001 | 100 | 0.10 €
FOJAN FRC0603F1000TS (Resistor 100Ω) | LCSC | C2906981 (https://www.lcsc.com/product-detail/C2906981.html) | 0.001 | 100 | 0.10 €
FOJAN FRC0603J470 TS (Resistor 47Ω) | LCSC | C2907174 (https://www.lcsc.com/product-detail/C2907174.html) | 0.001 | 100 | 0.10 €
FOJAN FRC0603F1R00TS (Resistor 1Ω) | LCSC | C2907004 (https://www.lcsc.com/product-detail/C2907004.html) | 0.0013 | 100 | 0.13 €
MICROCHIP ATTINY1614-SSN | LCSC (https://www.lcsc.com/) | C614832 (https://www.lcsc.com/product-detail/C614832.html) | 1.66 | 2 | 3.32 €
TI SN74LVC125ADR | LCSC (https://www.lcsc.com/) | C7661 (https://www.lcsc.com/product-detail/C7661.html) | 0.35 | 2 | 0.70 €
Bosch BME280 | LCSC (https://www.lcsc.com/) | C92489 (https://www.lcsc.com/product-detail/C92489.html) | 4.05 | 1 | 4.05 €
ADI AD8552ARZ-REEL7 | LCSC (https://www.lcsc.com/) | C9642 (https://www.lcsc.com/product-detail/C9642.html) | 2.85 | 1 | 2.85 €
 |  |  |  |  | 0.00 €
Livraison et expédition |  |  |  |  | 0.00 €
 |  |  |  | Total (TTC) | 59.01 €

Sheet: Mouser
Commentaire | Fournisseur | RefFournisseur | PrixUnitaire (TTC) | Quantitée | PrixTotal (TTC)
MICS-6814 | Mouser | 523-MICS-6814 (https://www.mouser.fr/ProductDetail/Amphenol-SGX-Sensortech/MICS-6814?qs=YCa/AAYMW01pNK%252BnW3Jo7g==) | 7.12 | 1 | 7.12 €
 |  |  |  |  | 7.12 €
Livraison et expédition |  |  |  |  | 0.00 €
 |  |  |  | Total (TTC) | 7.12 €

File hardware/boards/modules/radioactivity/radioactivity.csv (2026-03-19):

Reference | Qty | Value | DNP | Exclude from BOM | Exclude from Board | Footprint | Datasheet
100R1 | 1 | Potentiometer
C1,C2 | 2 | 100uF |  | Excluded from BOM
C3,C7,C8,C11,C12 | 5 | 100nF |  | Excluded from BOM
C4 | 1 | 1n |  | Excluded from BOM
C5,C9,C10 | 3 | 10n 1000V
C6 | 1 | 270pF
D1 | 1 | ~ |  | Excluded from BOM
D2,D3,D4 | 3 | ES1J
G1 | 1 | Geiger Tube |  | Excluded from BOM
g2 | 1 | TEST |  | Excluded from BOM
G3 | 1 | GPIO |  | Excluded from BOM
J1,J3 | 2 | jmp1 |  | Excluded from BOM
J2 | 1 | Programming Header |  | Excluded from BOM
L1 | 1 | 100uH
L2 | 1 | 10mH
Q1,Q3,Q4 | 3 | S8050
Q2 | 1 | MMBTA42
R1,R2 | 2 | 33k
R3 | 1 | 3k
R4 | 1 | 100k
R5,R13,R14,R15,R16,R17 | 6 | 10M
R6,R12 | 2 | 10K
R7,R9,R10 | 3 | 470K
R8 | 1 | 47K
R11 | 1 | 1K |  | Excluded from BOM
S1 | 1 | Speaker
U1,U2 | 2 | TLC555
U3 | 1 | ATTINY1614
U4 | 1 | SN74LVC125

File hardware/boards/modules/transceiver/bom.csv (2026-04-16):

Reference | Qty | Value | Footprint | Mfr. Part | LCSC
J1 | 1 | ~ | connector:Pin_02x04
J2 | 1 | SMA | connector:SMA
C8,C13,C14,C15,C16 | 5 | 1.5pF | common:C_0402 | 0402CG1R5C500NT | C1552
U1 | 1 | NRF24L01 | transceiver:NRF24L01_QFN20 | NRF24L01P-R | C8791
Y1 | 1 | 16MHz | common:Crystal_3225 | X322516MLB4SI | C13738
C3 | 1 | 1nF | common:C_0402 | CL05B102KB5NNNC | C14442
U2 | 1 | RFX2401C | transceiver:RFX2401C_QFN16 | RFX2401C | C19213
R2 | 1 | 1M | common:R_0402 | 0402WGF1004TCE | C26083
C2 | 1 | 10nF | common:C_0402 | CC0402KRX7R9BB103 | C60133
C6 | 1 | 2.2nF | common:C_0402 | CC0402KRX7R9BB222 | C106861
C10 | 1 | 220pF | common:C_0402 | CC0402JRNPO9BN221 | C107001
L4,L5 | 2 | 2.4nH | common:L_0402 | LQW15AN2N4B00D | C113113
C7 | 1 | 4.7pF | common:C_0402 | CC0402CRNPO9BN4R7 | C189469
C1 | 1 | 33nF | common:C_0402 | 0402B333K160CT | C301939
C11 | 1 | 1uF | common:C_0402 | CL05B105KQ5NQNC | C307427
L1 | 1 | 8.2nH | common:L_0402 | LQW15AN8N2G80D | C307610
C9 | 1 | 1pF | common:C_0402 | CC0402BRNPO9BN1R0 | C309455
L2 | 1 | 2.7nH | common:L_0402 | LQW15AN2N7G80D | C412269
L3 | 1 | 3.9nH | common:L_0402 | LQW15AN3N9G80D | C412279
C4,C5 | 2 | 12pF | common:C_0402 | CC0402GRNPO9BN120 | C526985
C12 | 1 | 0.3pF | common:C_0402 | 0402CG0R3B500NT | C880415
R3,R5 | 2 | 1k | common:R_0402 | FRC0402F1001TS | C2906864
R4 | 1 | 20k | common:R_0402 | FRC0402F2002TS | C2906867
R1 | 1 | 22k | common:R_0402 | FRC0402F2202TS | C2909337

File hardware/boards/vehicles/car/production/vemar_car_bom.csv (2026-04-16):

Designator | Footprint | Quantity | Value | LCSC Part #
BT1 | JST_XH_B2B-XH-A_1x02_P2.50mm_Vertical | 1 | JST
BZ1 | buzzer_8.5x8.5 | 1 | Buzzer
C1, C10, C11, C16, C18, C21, C23, C5, C6, C7, C8 | 0603 | 11 | 100nF
C12, C13 | 0603 | 2 | 22uF
C14 | 0603 | 1 | 75pF
C15, C17 | CP_Elec_6.3x5.4 | 2 | 22uF
C19 | 0603 | 1 | 10uF
C2, C3 | 0603 | 2 | 12pF
C20, C22 | CP_Elec_8x10.5 | 2 | 470uF
C4 | 0603 | 1 | 4.7uF
C9 | CP_Elec_4x5.4 | 1 | 10uF
D1, D3 | 0603 | 2 | RED
D10, D11, D12, D5, D6, D7, D8, D9 | SMA(DO-214AC) | 8 | SS36
D2 | 0603 | 1 | GREEN
D4 | D_SOD123 | 1 | RS1MFA
J1 | PinHeader_1x06_P2.54mm_Vertical | 1 | Dupont
J2 | PinHeader_1x04_P2.54mm_Vertical | 1 | Dupont
J3 | Pin_02x04 | 1 | Dupont
J4, J5, J6 | JST_XH_B5B-XH-A_1x05_P2.50mm_Vertical | 3 | JST
L1 | Inductor_octogone | 1 | 10uH
M1 | JST_XH_B2B-XH-A_1x02_P2.50mm_Vertical | 1 | LEFT
M2 | JST_XH_B2B-XH-A_1x02_P2.50mm_Vertical | 1 | RIGHT
Q1, Q2, Q7, Q8 | TO-220-3_Vertical | 4 | FQP27P06
Q10, Q3, Q4, Q9 | SOT-23 | 4 | AO3400A
Q11, Q12, Q5, Q6 | TO-92_Inline | 4 | 2N3904
R1 | 0603 | 1 | 680
R10 | 0603 | 1 | 43.2K
R11 | 0603 | 1 | 5.76K
R12 | 0603 | 1 | 1
R13, R14, R2, R21, R22, R29, R30 | 0603 | 7 | 10K
R15, R16, R23, R24 | 0603 | 4 | 1K
R17, R18, R25, R26 | 0603 | 4 | 47
R19, R20, R27, R28, R6, R7 | 0603 | 6 | 4.7K
R3, R4 | 0603 | 2 | 330
R5 | 0603 | 1 | ?
R8 | 0603 | 1 | 511K
R9 | 0603 | 1 | 105K
SD1 | SD_SLOT | 1 | SD Card Slot
SW1 | SW_Tactile3x2.5 | 1 | SW_Push
U1 | TQFP-32_7x7mm_P0.8mm | 1 | ATmega328P-A
U2 | TSOT-23-6_HandSoldering | 1 | TPS54302
U3 | SOT-223-3_TabPin2 | 1 | AMS1117-3.3
Y1 | crys_osc_smd3225_4 | 1 | 16MHz

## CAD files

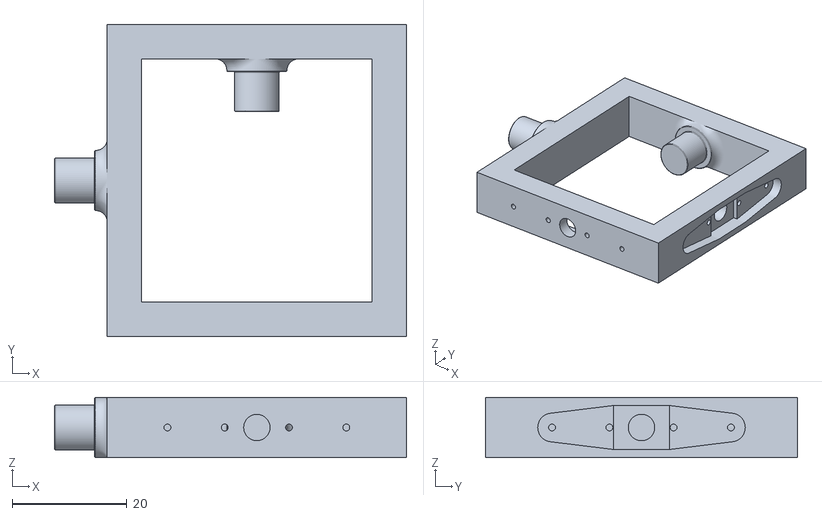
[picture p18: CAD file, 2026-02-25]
mechanical/export/lidar/pivot_frame.stl
61.4 x 54.4 x 10.5

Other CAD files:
mechanical/cad_src/Lidar.f3z
mechanical/cad_src/hardware/Bearing 608.f3d
mechanical/cad_src/hardware/Lidar X2L.f3d
mechanical/cad_src/hardware/Motor 36GP-3530.f3d
mechanical/cad_src/hardware/Servo Motor SG90.f3d

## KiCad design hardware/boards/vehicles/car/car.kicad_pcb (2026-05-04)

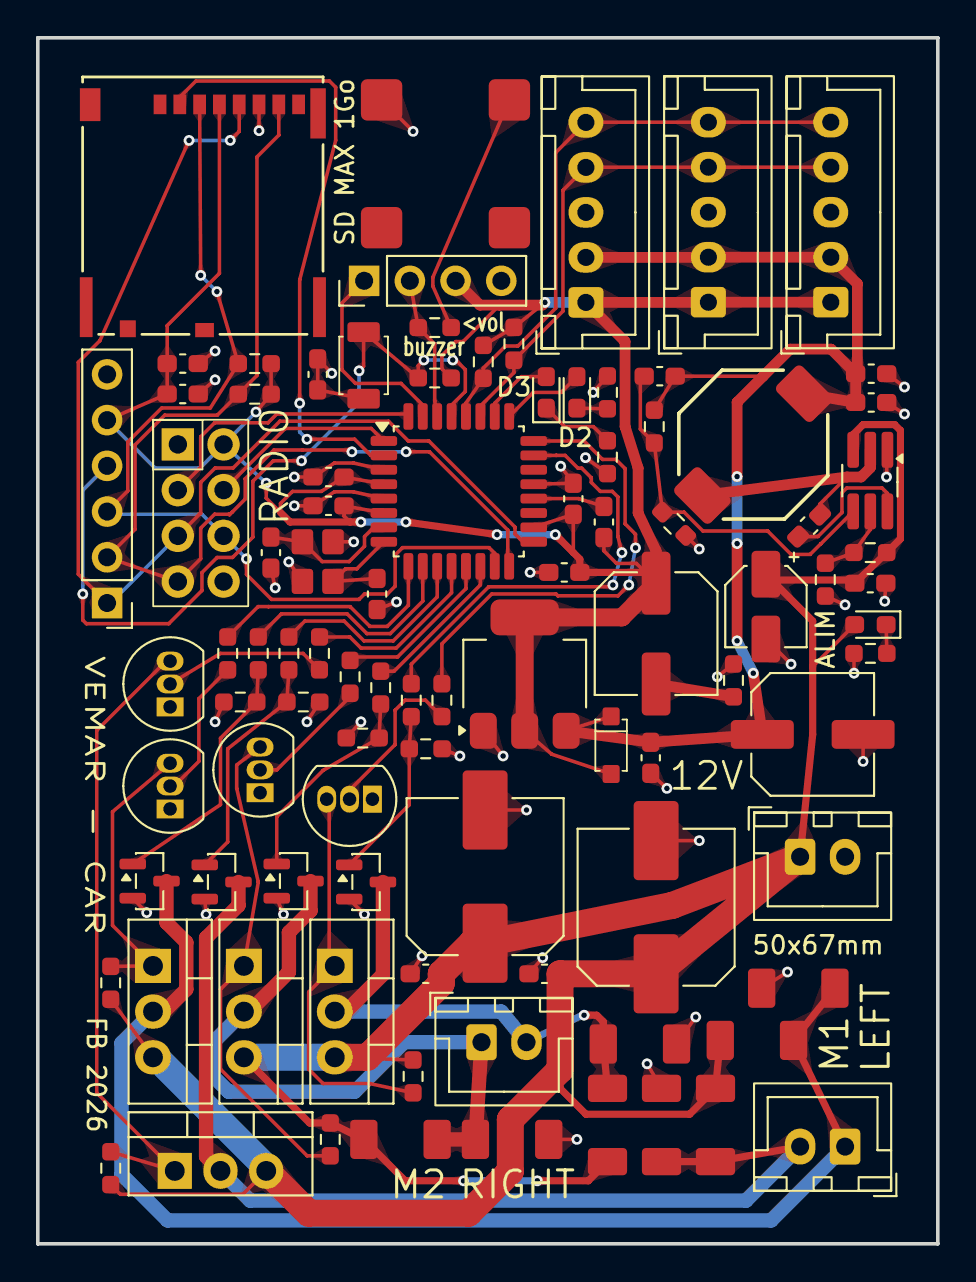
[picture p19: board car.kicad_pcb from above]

Board: 2 copper layers, 50.0 x 67.0 mm, 94 parts (0 on the bottom side), 53 nets.

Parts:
BT1: JST; JST_XH_B2B-XH-A_1x02_P2.50mm_Vertical
BZ1: Buzzer; buzzer_8.5x8.5
C1, C5, C6, C7, C8, C10, C11, C16, C18, C21, C23: 100nF; C_0603_1608Metric_Pad1.08x0.95mm_HandSolder
C2, C3: 12pF; C_0603_1608Metric_Pad1.08x0.95mm_HandSolder
C4: 4.7uF; C_0603_1608Metric_Pad1.08x0.95mm_HandSolder
C9: 10uF; CP_Elec_4x5.4
C12, C13: 22uF; C_0603_1608Metric_Pad1.08x0.95mm_HandSolder
C14: 75pF; C_0603_1608Metric_Pad1.08x0.95mm_HandSolder
C15, C17: 22uF; CP_Elec_6.3x5.4
C19: 10uF; C_0603_1608Metric_Pad1.08x0.95mm_HandSolder
C20, C22: 470uF; CP_Elec_8x10.5
D1, D3: RED; LED_0603_1608Metric_Pad1.05x0.95mm_HandSolder
D2: GREEN; LED_0603_1608Metric_Pad1.05x0.95mm_HandSolder
D4: RS1MFA; D_SOD123
D5, D6, D7, D8, D9, D10, D11, D12: SS36; SMA(DO-214AC)
J1: Dupont; PinHeader_1x06_P2.54mm_Vertical
J2: Dupont; PinHeader_1x04_P2.54mm_Vertical
J3: Dupont; Pin_02x04
J4, J5, J6: JST; JST_XH_B5B-XH-A_1x05_P2.50mm_Vertical
L1: 10uH; Inductor_octogone
M1: LEFT; JST_XH_B2B-XH-A_1x02_P2.50mm_Vertical
M2: RIGHT; JST_XH_B2B-XH-A_1x02_P2.50mm_Vertical
Q1, Q2, Q7, Q8: FQP27P06; TO-220-3_Vertical
Q3, Q4, Q9, Q10: AO3400A; SOT-23
Q5, Q6, Q11, Q12: 2N3904; TO-92_Inline
R1: 680; R_0603_1608Metric_Pad0.98x0.95mm_HandSolder
R2, R13, R14, R21, R22, R29, R30: 10K; R_0603_1608Metric_Pad0.98x0.95mm_HandSolder
R3, R4: 330; R_0603_1608Metric_Pad0.98x0.95mm_HandSolder
R5: ?; R_0603_1608Metric_Pad0.98x0.95mm_HandSolder
R6, R7, R19, R20, R27, R28: 4.7K; R_0603_1608Metric_Pad0.98x0.95mm_HandSolder
R8: 511K; R_0603_1608Metric_Pad0.98x0.95mm_HandSolder
R9: 105K; R_0603_1608Metric_Pad0.98x0.95mm_HandSolder
R10: 43.2K; R_0603_1608Metric_Pad0.98x0.95mm_HandSolder
R11: 5.76K; R_0603_1608Metric_Pad0.98x0.95mm_HandSolder
R12: 1; R_0603_1608Metric_Pad0.98x0.95mm_HandSolder
R15, R16, R23, R24: 1K; R_0603_1608Metric_Pad0.98x0.95mm_HandSolder
R17, R18, R25, R26: 47; R_0603_1608Metric_Pad0.98x0.95mm_HandSolder
SD1: SD Card Slot; SD_SLOT
SW1: SW_Push; SW_Tactile3x2.5
U1: ATmega328P-A; TQFP-32_7x7mm_P0.8mm
U2: TPS54302; TSOT-23-6_HandSoldering
U3: AMS1117-3.3; SOT-223-3_TabPin2
Y1: 16MHz; crys_osc_smd3225_4

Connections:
3V3: C4.1, C5.1, C6.1, C7.1, C8.1, C17.1, C18.1, C19.1, D4.2 (A), J1.5, J2.3, J3.8, J4.1, J5.1, J6.1, R2.1, R6.1, R7.1, R13.1, R14.1, SD1.4 (VDD), U1.4 (VCC), U1.6 (VCC), U1.18 (AVCC), U3.2 (VO)
5V: C12.1, C13.2, C14.2, C15.1, C16.2, D4.1 (K), J4.2, J5.2, J6.2, L1.2, R10.2, U3.3 (VI)
12V: BT1.1 (+), C9.1, C10.2, C20.1, C21.1, C22.1, C23.1, D1.2 (A), D5.1 (K), D7.1 (K), D9.1 (K), D11.1 (K), Q1.3 (S), Q2.3 (S), Q7.3 (S), Q8.3 (S), R8.2, R19.2, R20.1, R27.2, R28.1, U2.3 (VIN)
D2: D2.2 (A), U1.25 (PC2)
D3: D3.2 (A), U1.26 (PC3)
GND: BT1.2 (-), BZ1.2, C1.1, C1.2, C2.2, C3.2, C4.2, C5.2, C6.2, C7.2, C9.2, C10.1, C12.2, C13.1, C15.2, C16.1, C18.2, C19.2, C20.2, C21.2, C22.2, C23.2, D6.2 (A), D8.2 (A), D10.2 (A), D12.2 (A), J1.6, J2.4, J3.1, J4.3, J5.3, J6.3, Q3.2 (S), Q4.2 (S), Q5.1 (E), Q6.1 (E), Q9.2 (S), Q10.2 (S), Q11.1 (E), Q12.1 (E), R1.2, R3.2, R4.2, R9.1, R11.1, R12.1, R21.2, R22.1, R29.2, R30.1, SD1.6 (VSS), SW1.1, U1.3 (GND), U1.5 (GND), U1.21 (GND), U2.1 (GND), U3.1 (GND), Y1.2 (G), Y1.4 (G)
M1_EN_CCW: R16.1, U1.12 (PB0)
M1_EN_CW: R18.2, U1.11 (PD7)
M1_PWM_CCW: R17.2, U1.10 (PD6)
M1_PWM_CW: R15.1, U1.9 (PD5)
M2_EN_CCW: R24.1, U1.24 (PC1)
M2_EN_CW: R26.2, U1.23 (PC0)
M2_PWM_CCW: R25.2, U1.14 (PB2)
M2_PWM_CW: R23.1, U1.13 (PB1)
MISO: J1.2, J3.4, R14.2, SD1.7 (DAT0), U1.16 (PB4)
MOSI: J1.3, J3.6, R13.2, SD1.3 (CMD), U1.15 (PB3)
unnamed: BZ1.1, R5.2
unnamed: C17.2, R12.2
unnamed: D1.1 (K), R1.1
unnamed: D2.1 (K), R3.1
unnamed: D3.1 (K), R4.1
unnamed: D5.2 (A), D6.1 (K), M1.1 (+), Q1.2 (D), Q3.3 (D)
unnamed: D7.2 (A), D8.1 (K), M1.2 (-), Q2.2 (D), Q4.3 (D)
unnamed: D9.2 (A), D10.1 (K), M2.1 (+), Q7.2 (D), Q9.3 (D)
unnamed: D11.2 (A), D12.1 (K), M2.2 (-), Q8.2 (D), Q10.3 (D)
unnamed: Q1.1 (G), Q5.3 (C), R19.1
unnamed: Q2.1 (G), Q6.3 (C), R20.2
unnamed: Q3.1 (G), R17.1, R21.1
unnamed: Q4.1 (G), R18.1, R22.2
unnamed: Q5.2 (B), R15.2
unnamed: Q6.2 (B), R16.2
unnamed: Q9.1 (G), R25.1, R29.1
unnamed: Q10.1 (G), R26.1, R30.2
unnamed: Q11.2 (B), R23.2
unnamed: Q7.1 (G), Q11.3 (C), R27.1
unnamed: Q12.2 (B), R24.2
unnamed: Q8.1 (G), Q12.3 (C), R28.2
unnamed: C8.2, U1.20 (AREF)
unnamed: C2.1, U1.7 (XTAL1/PB6), Y1.1
unnamed: C3.1, U1.8 (XTAL2/PB7), Y1.3
unnamed: C11.1, U2.6 (BOOT)
unnamed: R8.1, R9.2, U2.5 (EN)
unnamed: C14.1, R10.1, R11.2, U2.4 (FB)
unnamed: C11.2, L1.1, U2.2 (SW)
RC_CS: J3.7, U1.1 (PD3)
RC_EN: J3.2, U1.32 (PD2)
RST: J1.4, R2.2, SW1.2, U1.29 (~RESET/PC6)
RX: J2.2, R5.1, U1.30 (PD0)
SCK: J1.1, J3.3, SD1.5 (CLK), U1.17 (PB5)
SCL: J4.5, J5.5, J6.5, R7.2, U1.28 (PC5)
SDA: J4.4, J5.4, J6.4, R6.2, U1.27 (PC4)
SD_CS: SD1.2 (CD/DAT3), U1.2 (PD4)
TX: J2.1, U1.31 (PD1)

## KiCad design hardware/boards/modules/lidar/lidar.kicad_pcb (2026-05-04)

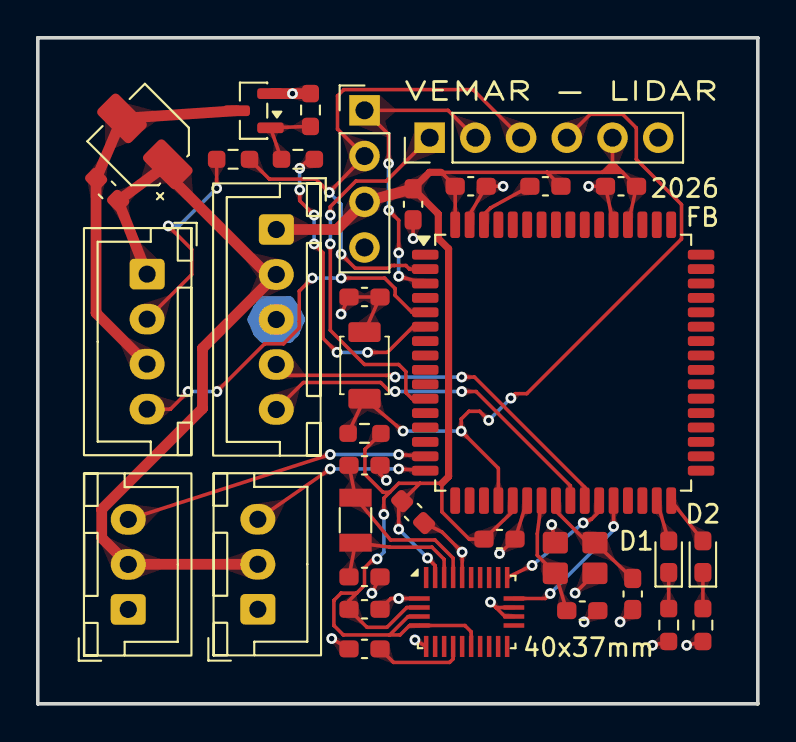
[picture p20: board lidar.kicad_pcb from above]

Board: 2 copper layers, 40.0 x 37.0 mm, 35 parts (0 on the bottom side), 28 nets.

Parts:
C1, C5, C6, C7, C8, C10, C13, C14: 100nF; C_0603_1608Metric_Pad1.08x0.95mm_HandSolder
C2, C3, C11, C12: 12pF; C_0603_1608Metric_Pad1.08x0.95mm_HandSolder
C4: 4.7uF; C_0603_1608Metric_Pad1.08x0.95mm_HandSolder
C9: 10uF; CP_Elec_4x5.4
C15: 1uF; C_0603_1608Metric_Pad1.08x0.95mm_HandSolder
D1: GREEN; LED_0603_1608Metric_Pad1.05x0.95mm_HandSolder
D2: RED; LED_0603_1608Metric_Pad1.05x0.95mm_HandSolder
J1: JST; JST_XH_B5B-XH-A_1x05_P2.50mm_Vertical
J2: Dupont; PinHeader_1x06_P2.54mm_Vertical
J3: Dupont; PinHeader_1x04_P2.54mm_Vertical
J4: JST; JST_XH_B4B-XH-A_1x04_P2.50mm_Vertical
J5, J6: JST; JST_XH_B3B-XH-A_1x03_P2.50mm_Vertical
Q1: AO3400A; SOT-23
R1, R5: 10K; R_0603_1608Metric_Pad0.98x0.95mm_HandSolder
R2, R3: 330; R_0603_1608Metric_Pad0.98x0.95mm_HandSolder
R4: 100; R_0603_1608Metric_Pad0.98x0.95mm_HandSolder
R6: 1K; R_0603_1608Metric_Pad0.98x0.95mm_HandSolder
SW1: SW_Push; SW_Tactile3x2.5
U1: ATmega128A; TQFP-64_14x14mm_P0.8mm
U2: BNO055; BNO055_Hand_Soldering_LGA-28_5.2x3.8mm_P0.5mm
Y1: 16MHz; crys_osc_smd3225_4
Y2: 32.768kHz; Crystal_SMD_3215-2Pin_3.2x1.5mm

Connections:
3V3: C4.1, C5.1, C6.1, C7.1, C8.1, C13.2, C14.1, J1.1 (3V3), J2.5, J3.3, R1.1, U1.21 (VCC), U1.52 (VCC), U1.64 (AVCC), U2.3 (VDD), U2.4 (~BOOT_LOAD_PIN), U2.5 (PS1), U2.11 (~RESET), U2.28 (VDDIO)
5V: C9.1, C10.1, J1.2 (5V), J4.1, J5.2, J6.2
D1: D1.2 (A), U1.31 (PD6)
D2: D2.2 (A), U1.32 (PD7)
GND: C1.1, C1.2, C2.2, C3.2, C4.2, C5.2, C6.2, C7.2, C11.2, C12.2, C13.1, C14.2, C15.2, J1.3 (GND), J2.6, J3.4, J5.1, J6.1, Q1.2 (S), R2.2, R3.2, R5.1, SW1.1, U1.22 (GND), U1.53 (GND), U1.63 (GND), U2.2 (GND), U2.6 (PS0), U2.17 (COM3), U2.18 (COM2), U2.25 (GNDIO), Y1.2 (G), Y1.4 (G)
LIDAR_EN: R4.1, U1.6 (PE4)
LIDAR_PWM: J4.4, U1.5 (PE3)
unnamed: D1.1 (K), R2.1
unnamed: D2.1 (K), R3.1
unnamed: J4.2, R6.2
unnamed: C9.2, C10.2, J4.3, Q1.3 (D)
unnamed: Q1.1 (G), R4.2, R5.2
unnamed: C8.2, U1.62 (AREF)
unnamed: C2.1, U1.24 (XTAL1), Y1.1
unnamed: C3.1, U1.23 (XTAL2), Y1.3
unnamed: C15.1, U2.9 (CAP)
unnamed: C12.1, U2.27 (XIN32), Y2.1
unnamed: C11.1, U2.26 (XOUT32), Y2.2
RST: J2.4, R1.2, SW1.2, U1.20 (~RESET)
RX0: J2.3, J3.2, R6.1, U1.2 (PE0)
RX1: U1.27 (PD2), U2.20 (COM0)
SCK: J2.1, U1.11 (PB1)
SCL: J1.5 (SCL), U1.25 (PD0)
SDA: J1.4 (SDA), U1.26 (PD1)
SERVO_A_PWM: J5.3, U1.15 (PB5)
SERVO_B_PWM: J6.3, U1.16 (PB6)
TX0: J2.2, J3.1, U1.3 (PE1)
TX1: U1.28 (PD3), U2.19 (COM1)

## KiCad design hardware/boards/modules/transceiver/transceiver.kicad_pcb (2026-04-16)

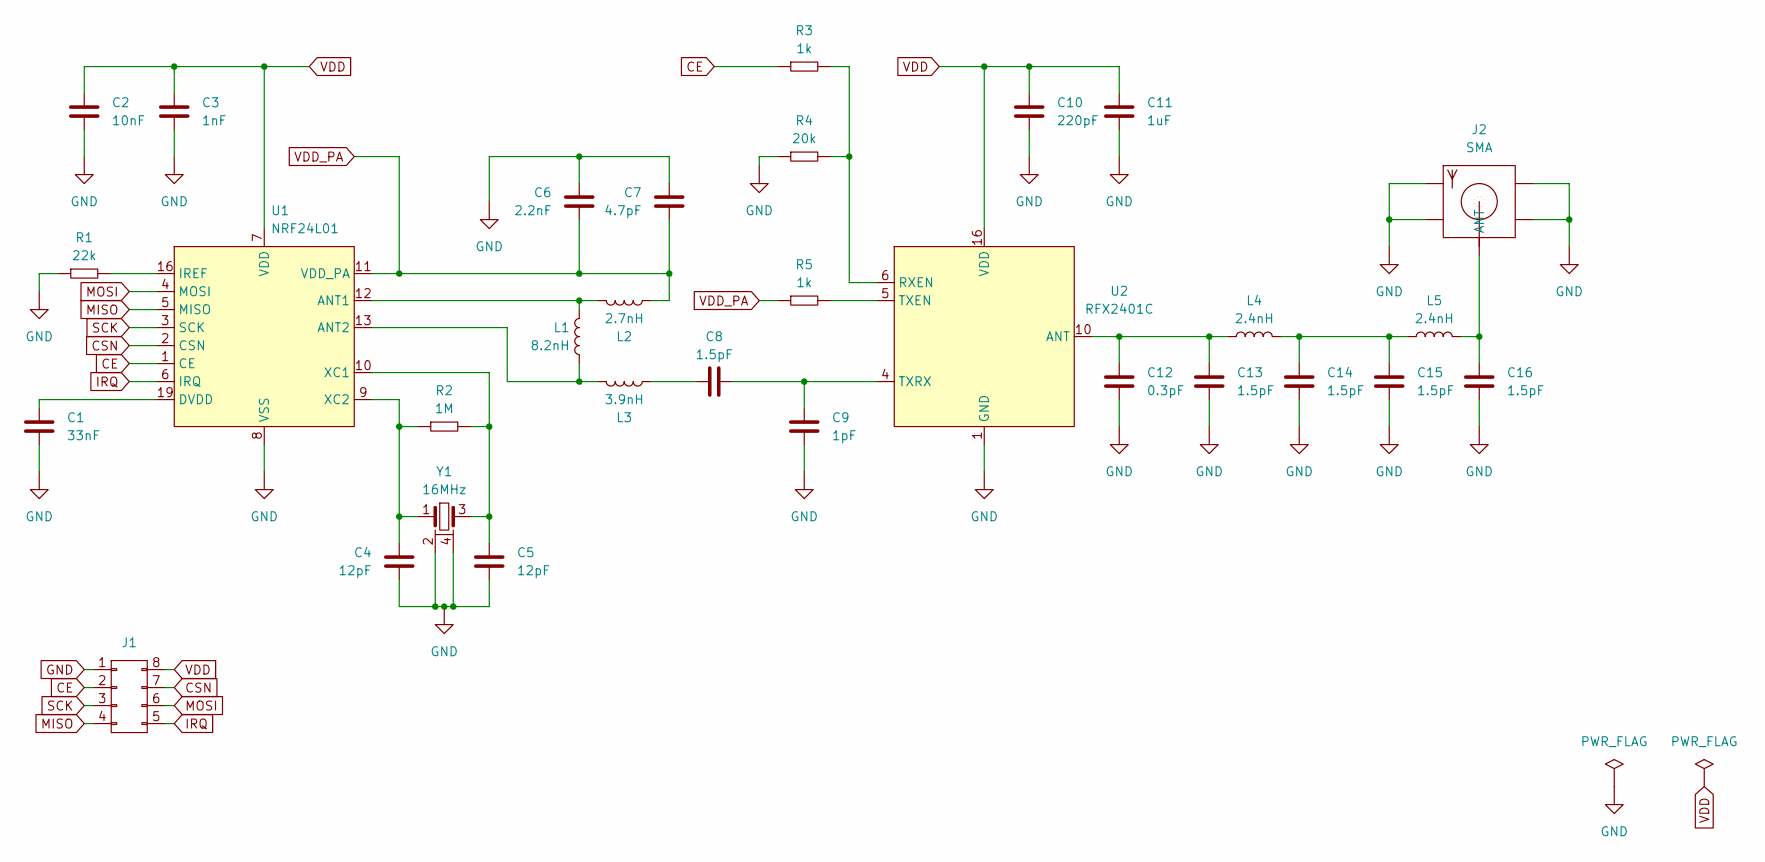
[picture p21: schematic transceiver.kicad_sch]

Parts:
C1: 33nF; C_0402; Mfr. Part 0402B333K160CT; LCSC C301939
C2: 10nF; C_0402; Mfr. Part CC0402KRX7R9BB103; LCSC C60133
C3: 1nF; C_0402; Mfr. Part CL05B102KB5NNNC; LCSC C14442
C4, C5: 12pF; C_0402; Mfr. Part CC0402GRNPO9BN120; LCSC C526985
C6: 2.2nF; C_0402; Mfr. Part CC0402KRX7R9BB222; LCSC C106861
C7: 4.7pF; C_0402; Mfr. Part CC0402CRNPO9BN4R7; LCSC C189469
C8, C13, C14, C15, C16: 1.5pF; C_0402; Mfr. Part 0402CG1R5C500NT; LCSC C1552
C9: 1pF; C_0402; Mfr. Part CC0402BRNPO9BN1R0; LCSC C309455
C10: 220pF; C_0402; Mfr. Part CC0402JRNPO9BN221; LCSC C107001
C11: 1uF; C_0402; Mfr. Part CL05B105KQ5NQNC; LCSC C307427
C12: 0.3pF; C_0402; Mfr. Part 0402CG0R3B500NT; LCSC C880415
J1: Pin_02x04
J2: SMA
L1: 8.2nH; L_0402; Mfr. Part LQW15AN8N2G80D; LCSC C307610
L2: 2.7nH; L_0402; Mfr. Part LQW15AN2N7G80D; LCSC C412269
L3: 3.9nH; L_0402; Mfr. Part LQW15AN3N9G80D; LCSC C412279
L4, L5: 2.4nH; L_0402; Mfr. Part LQW15AN2N4B00D; LCSC C113113
R1: 22k; R_0402; Mfr. Part FRC0402F2202TS; LCSC C2909337
R2: 1M; R_0402; Mfr. Part 0402WGF1004TCE; LCSC C26083
R3, R5: 1k; R_0402; Mfr. Part FRC0402F1001TS; LCSC C2906864
R4: 20k; R_0402; Mfr. Part FRC0402F2002TS; LCSC C2906867
U1: NRF24L01; NRF24L01_QFN20; Mfr. Part NRF24L01P-R; LCSC C8791
U2: RFX2401C; RFX2401C_QFN16; Mfr. Part RFX2401C; LCSC C19213
Y1: 16MHz; Crystal_3225; Mfr. Part X322516MLB4SI; LCSC C13738

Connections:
CE: J1.2, R3.1, U1.1 (CE)
CSN: J1.7, U1.2 (CSN)
IRQ: J1.5, U1.6 (IRQ)
MISO: J1.4, U1.5 (MISO)
MOSI: J1.6, U1.4 (MOSI)
unnamed: C8.2, L3.2
unnamed: C14.2, C15.2, L4.2, L5.1
unnamed: C16.2, J2.1 (ANT), L5.2
unnamed: L1.1, L2.1, U1.12 (ANT1)
unnamed: L1.2, L3.1, U1.13 (ANT2)
unnamed: C1.2, U1.19 (DVDD)
unnamed: R1.2, U1.16 (IREF)
unnamed: C5.2, R2.2, U1.10 (XC1), Y1.3
unnamed: C4.2, R2.1, U1.9 (XC2), Y1.1
unnamed: C12.2, C13.2, L4.1, U2.10 (ANT)
unnamed: R3.2, R4.2, U2.6 (RXEN)
unnamed: R5.2, U2.5 (TXEN)
unnamed: C8.1, C9.2, U2.4 (TXRX)
SCK: J1.3, U1.3 (SCK)
VDD_PA: C6.1, C7.2, L2.2, R5.1, U1.11 (VDD_PA)

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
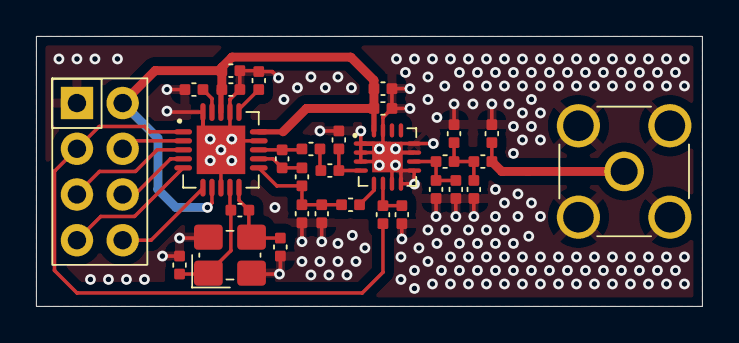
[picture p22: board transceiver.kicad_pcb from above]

Board: 2 copper layers, 37.0 x 15.0 mm, 31 parts (0 on the bottom side), 22 nets.

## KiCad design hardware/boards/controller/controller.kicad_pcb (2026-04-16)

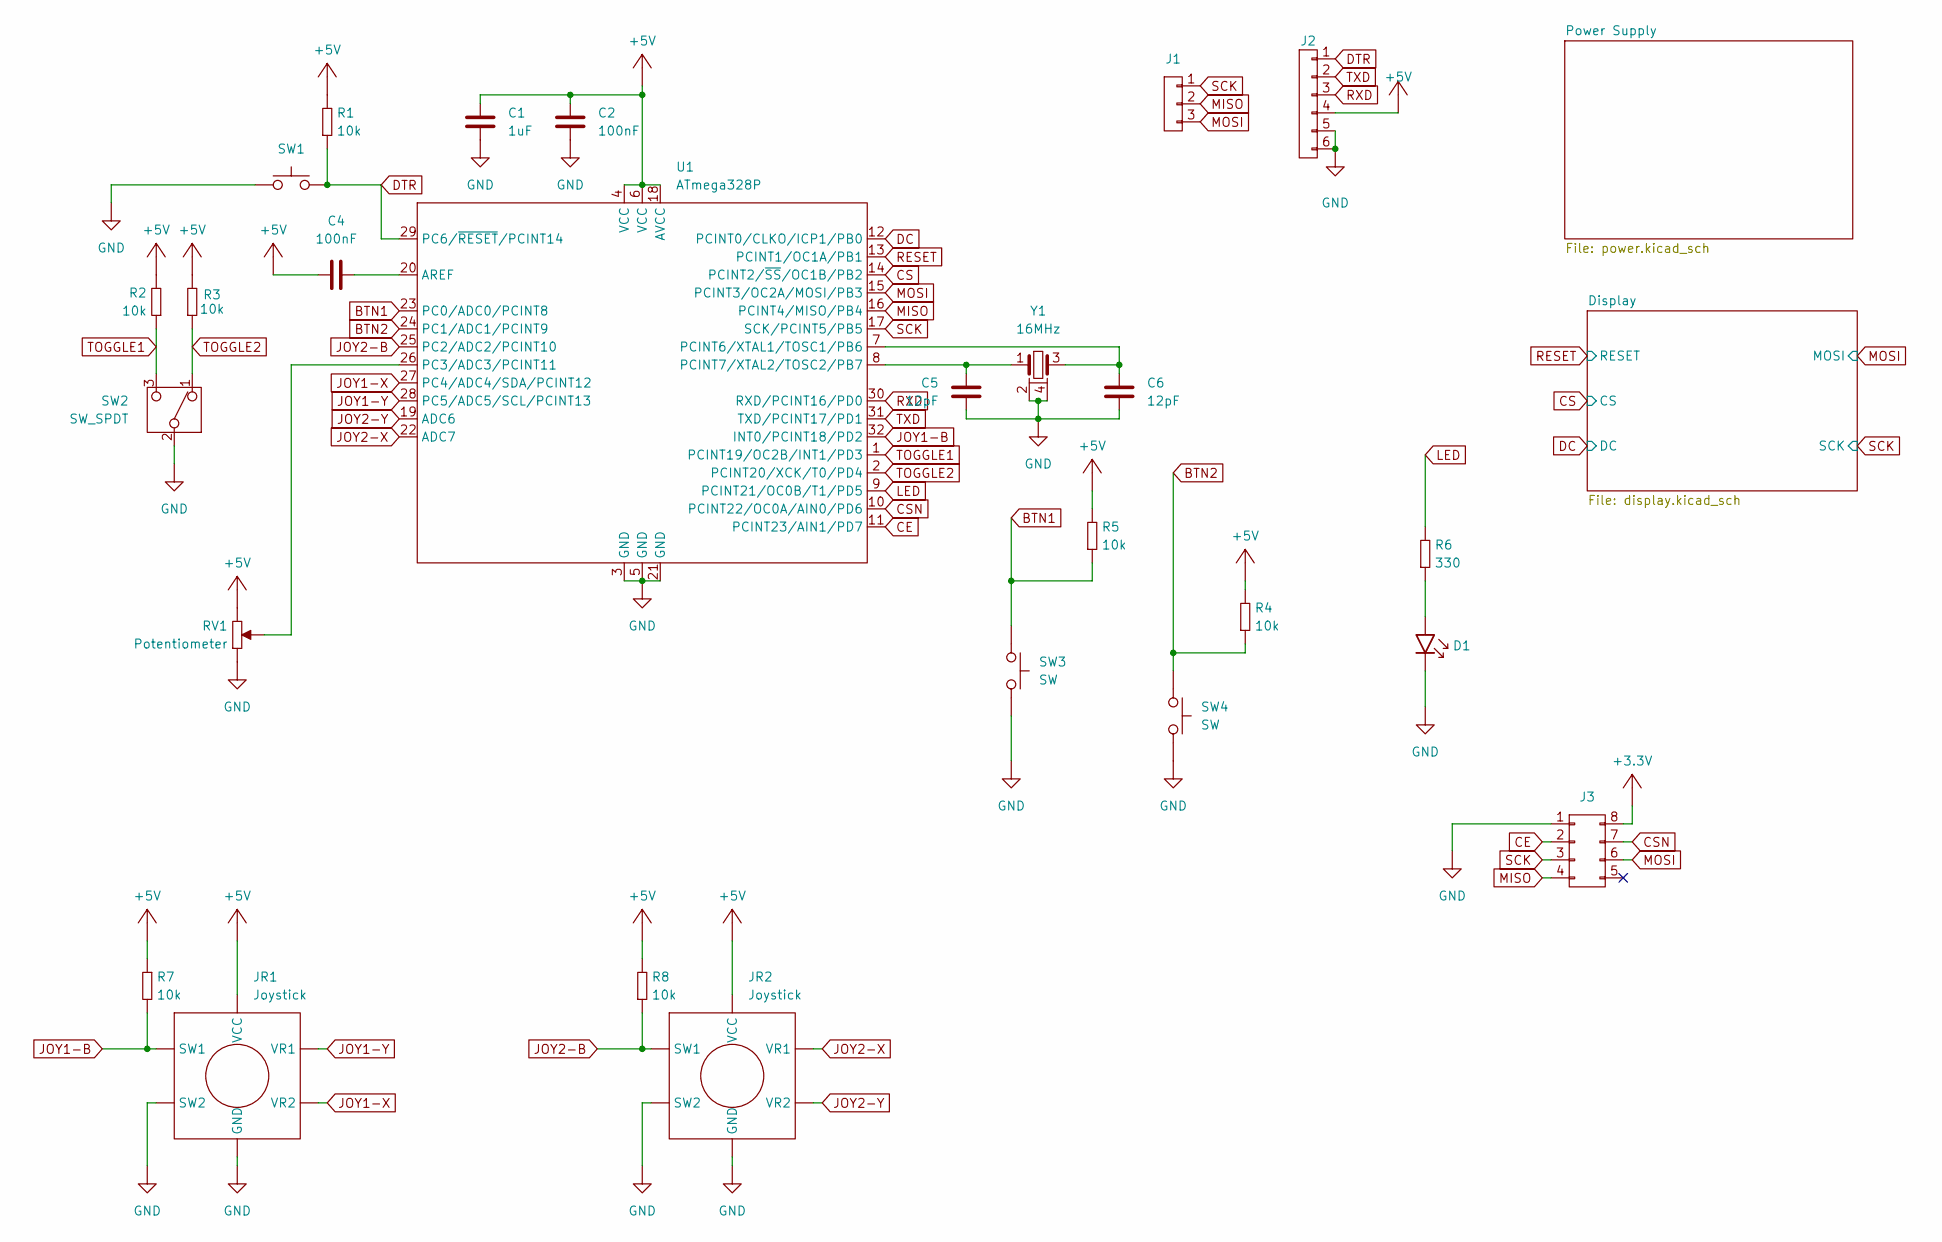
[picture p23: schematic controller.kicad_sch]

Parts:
C1: 1uF; C_0603; Manufacturer Part CL10A105KP8NNNC; LCSC Part C26413
C2, C4: 100nF; C_0603; Manufacturer Part CC0603KRX7R9BB104; LCSC Part C14663
C5, C6: 12pF; C_0603; Manufacturer Part CC0603JRNPO9BN120; LCSC Part C107034
D1: Green; LED_0603; Manufacturer Part YLED0603G; LCSC Part C19273151
J1: 01x03; Pin_01x03
J2: 01x06; Pin_01x06
J3: 02x04; Pin_02x04
JR1, JR2: Joystick; Manufacturer Part Hall-Effect Joysticks; LCSC Part AliExpress
R1, R2, R3, R4, R5, R7, R8: 10k; R_0603; Manufacturer Part FRC0603F1002TS; LCSC Part C2906982
R6: 330; R_0603; Manufacturer Part FRC0603J331 TS; LCSC Part C2907152
RV1: Potentiometer; RV_45; Manufacturer Part PTA4543-2015DPB103; LCSC Part C17444183
SW1: Reset; SW_Tactile3x2.5; Manufacturer Part HX-B3U-1000P-1.6N; LCSC Part C49234121
SW2: SW_SPDT; SW_Toggle; Manufacturer Part MST103; LCSC Part AliExpress
SW3, SW4: SW; SW_Tactile12x12; Manufacturer Part TS-1094TS-B3D2-T-Y; LCSC Part C19077684
U1: ATmega328P; ATmega328p_TQFP; Manufacturer Part ATMEGA328P-AU; LCSC Part C14877
Y1: 16MHz; Crystal_3225; Manufacturer Part X322516MLB4SI; LCSC Part C13738

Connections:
+3.3V: J3.8; also elsewhere on the board
+5V: C1.2, C2.2, C4.1, J2.4, JR1.1 (VCC), JR1.4 (VCC), JR2.1 (VCC), JR2.4 (VCC), R1.2, R2.2, R3.2, R4.2, R5.2, R7.1, R8.2, RV1.3, U1.4 (VCC), U1.6 (VCC), U1.18 (AVCC); also elsewhere on the board
BTN1: R5.1, SW3.1, SW3.2, U1.23 (PC0/ADC0/PCINT8)
BTN2: R4.1, SW4.1, SW4.2, U1.24 (PC1/ADC1/PCINT9)
CE: J3.2, U1.11 (PCINT23/AIN1/PD7)
CS: U1.14 (PCINT2/~SS/OC1B/PB2); also elsewhere on the board
CSN: J3.7, U1.10 (PCINT22/OC0A/AIN0/PD6)
DC: U1.12 (PCINT0/CLKO/ICP1/PB0); also elsewhere on the board
DTR: J2.1, R1.1, SW1.2, U1.29 (PC6/~RESET/PCINT14)
JOY1-B: JR1.7 (SW1), JR1.9 (SW1), R7.2, U1.32 (INT0/PCINT18/PD2)
JOY1-X: JR1.5 (VR2), U1.27 (PC4/ADC4/SDA/PCINT12)
JOY1-Y: JR1.2 (VR1), U1.28 (PC5/ADC5/SCL/PCINT13)
JOY2-B: JR2.7 (SW1), JR2.9 (SW1), R8.1, U1.25 (PC2/ADC2/PCINT10)
JOY2-X: JR2.2 (VR1), U1.22 (ADC7)
JOY2-Y: JR2.5 (VR2), U1.19 (ADC6)
LED: R6.2, U1.9 (PCINT21/OC0B/T1/PD5)
MISO: J1.2, J3.4, U1.16 (PCINT4/MISO/PB4)
MOSI: J1.3, J3.6, U1.15 (PCINT3/OC2A/MOSI/PB3); also elsewhere on the board
unnamed: D1.2 (A), R6.1
unnamed: C4.2, U1.20 (AREF)
unnamed: RV1.2, U1.26 (PC3/ADC3/PCINT11)
unnamed: C6.2, U1.7 (PCINT6/XTAL1/TOSC1/PB6), Y1.3
unnamed: C5.2, U1.8 (PCINT7/XTAL2/TOSC2/PB7), Y1.1
RESET: U1.13 (PCINT1/OC1A/PB1); also elsewhere on the board
RXD: J2.3, U1.30 (RXD/PCINT16/PD0)
SCK: J1.1, J3.3, U1.17 (SCK/PCINT5/PB5); also elsewhere on the board
TOGGLE1: R2.1, SW2.3, U1.1 (PCINT19/OC2B/INT1/PD3)
TOGGLE2: R3.1, SW2.1, U1.2 (PCINT20/XCK/T0/PD4)
TXD: J2.2, U1.31 (TXD/PCINT17/PD1)

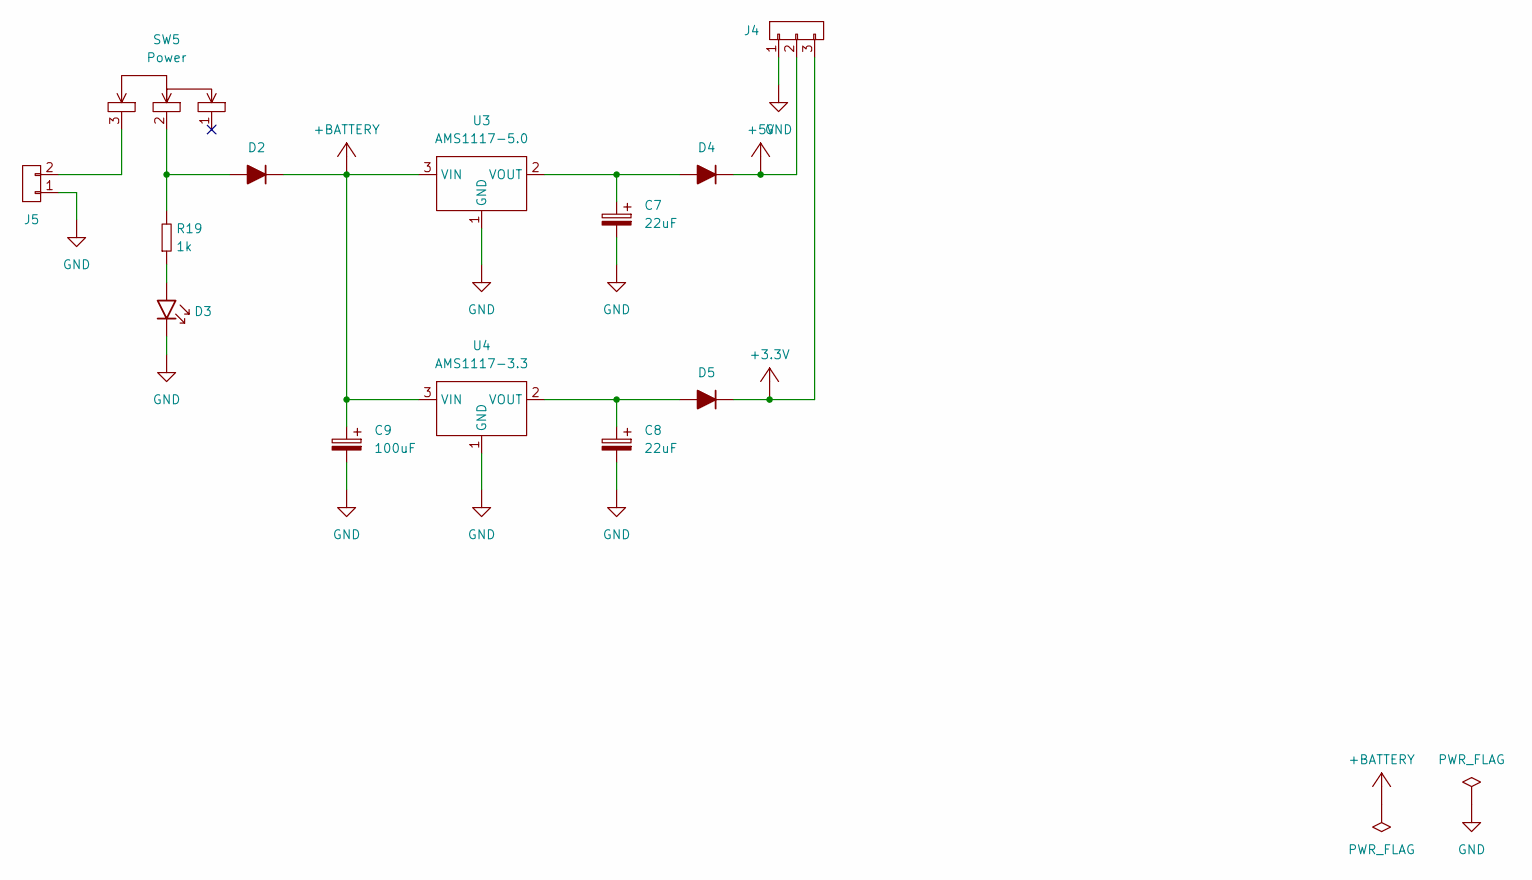
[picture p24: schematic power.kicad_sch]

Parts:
C7, C8: 22uF; C_D6.3xL5.4; Manufacturer Part RVT1H220M0605; LCSC Part C72505
C9: 100uF; C_D6.3xL5.4; Manufacturer Part RVT1V101M0605; LCSC Part C3151830
D2, D4, D5: Diode; D_SOD123FL; Manufacturer Part 1N4001W; LCSC Part C18199085
D3: Red; LED_0603; Manufacturer Part YLED0603R; LCSC Part C19171390
J4: 01x03; Pin_01x03
J5: 01x02; Pin_01x02
R19: 1k; R_0603; Manufacturer Part FRC0603J102 TS; LCSC Part C2907113
SW5: Power; SW_Slide9.1x3.5; Manufacturer Part MST-12D18G4 SPDT Slide Switch; LCSC Part C49023767
U3: AMS1117-5.0; AMS1117-SOT223; Manufacturer Part AMS1117-3.3; LCSC Part C347222
U4: AMS1117-3.3; AMS1117-SOT223; Manufacturer Part AMS1117-5.0; LCSC Part C347223

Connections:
+3.3V: D5.1 (K), J4.3; also elsewhere on the board
+5V: D4.1 (K), J4.2; also elsewhere on the board
unnamed: D2.2 (A), R19.2, SW5.2
unnamed: D3.2 (A), R19.1
unnamed: C7.1, D4.2 (A), U3.2 (VOUT)
unnamed: C8.1, D5.2 (A), U4.2 (VOUT)
unnamed: J5.2, SW5.3

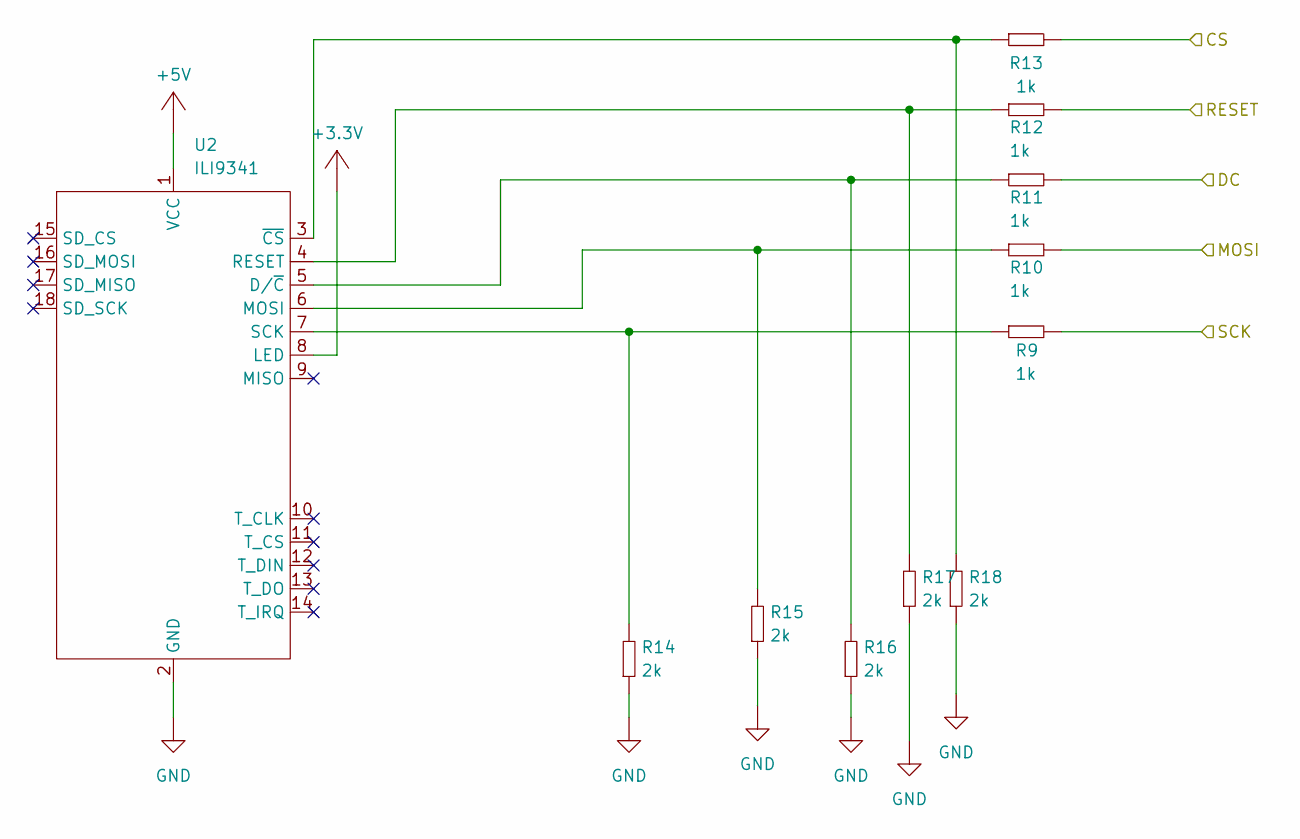
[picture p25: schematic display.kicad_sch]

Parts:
R9, R10, R11, R12, R13: 1k; R_0603; Manufacturer Part FRC0603J102 TS; LCSC Part C2907113
R14, R15, R16, R17, R18: 2k; R_0603; Manufacturer Part FRC0603F2001TS; LCSC Part C2907022
U2: ILI9341

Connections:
+3.3V: U2.8 (LED); also elsewhere on the board
+5V: U2.1 (VCC); also elsewhere on the board
CS: R13.2; also elsewhere on the board
DC: R11.2; also elsewhere on the board
MOSI: R10.2; also elsewhere on the board
unnamed: R11.1, R16.2, U2.5 (D/~C)
unnamed: R10.1, R15.2, U2.6 (MOSI)
unnamed: R12.1, R17.2, U2.4 (RESET)
unnamed: R9.1, R14.2, U2.7 (SCK)
unnamed: R13.1, R18.2, U2.3 (~CS)
RESET: R12.2; also elsewhere on the board
SCK: R9.2; also elsewhere on the board

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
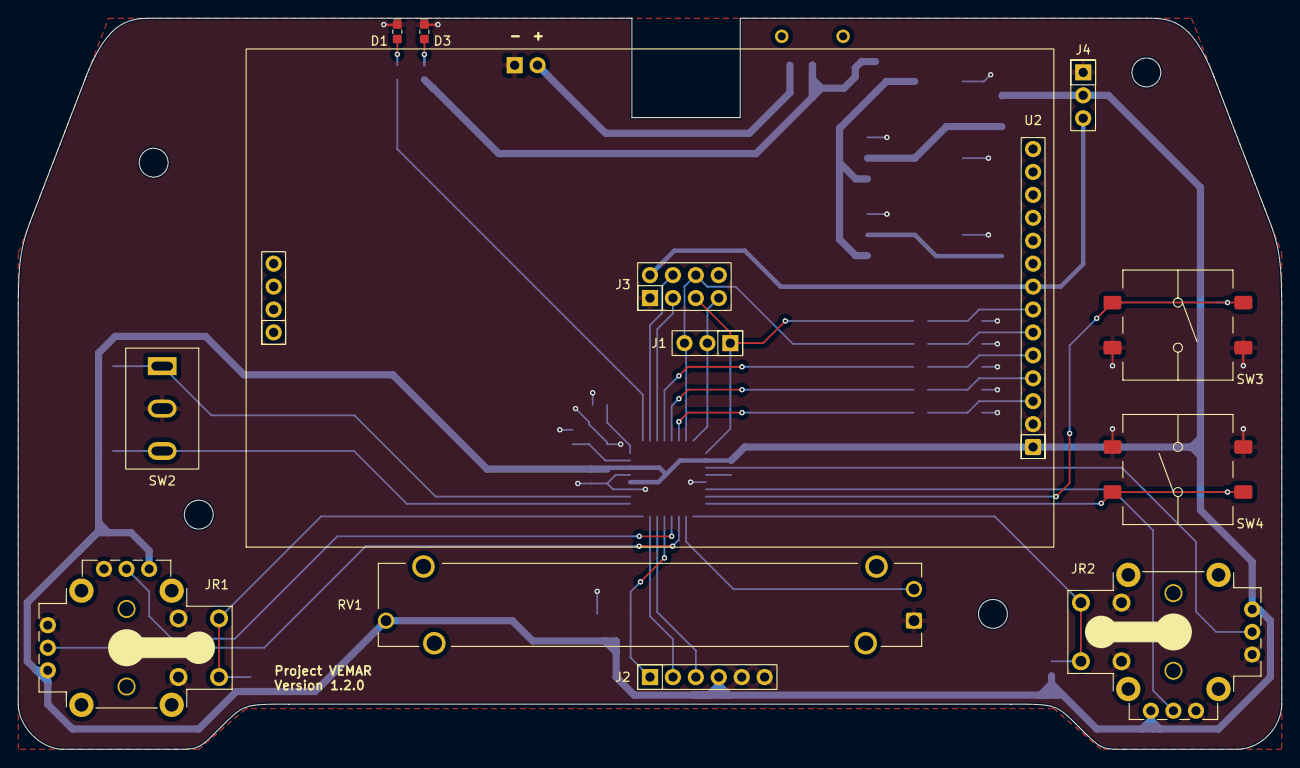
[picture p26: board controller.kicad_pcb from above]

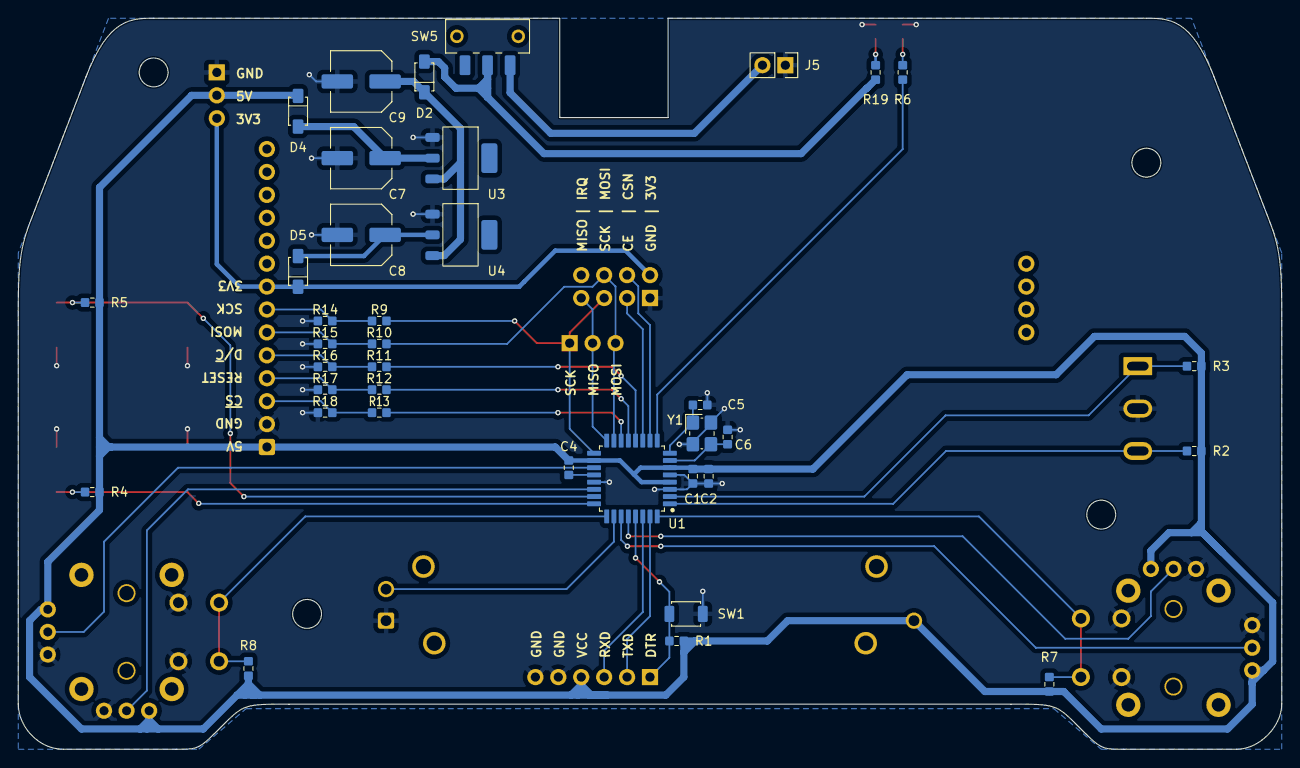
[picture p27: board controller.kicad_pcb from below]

Board: 2 copper layers, 140.0 x 81.0 mm, 50 parts (37 on the bottom side), 41 nets.

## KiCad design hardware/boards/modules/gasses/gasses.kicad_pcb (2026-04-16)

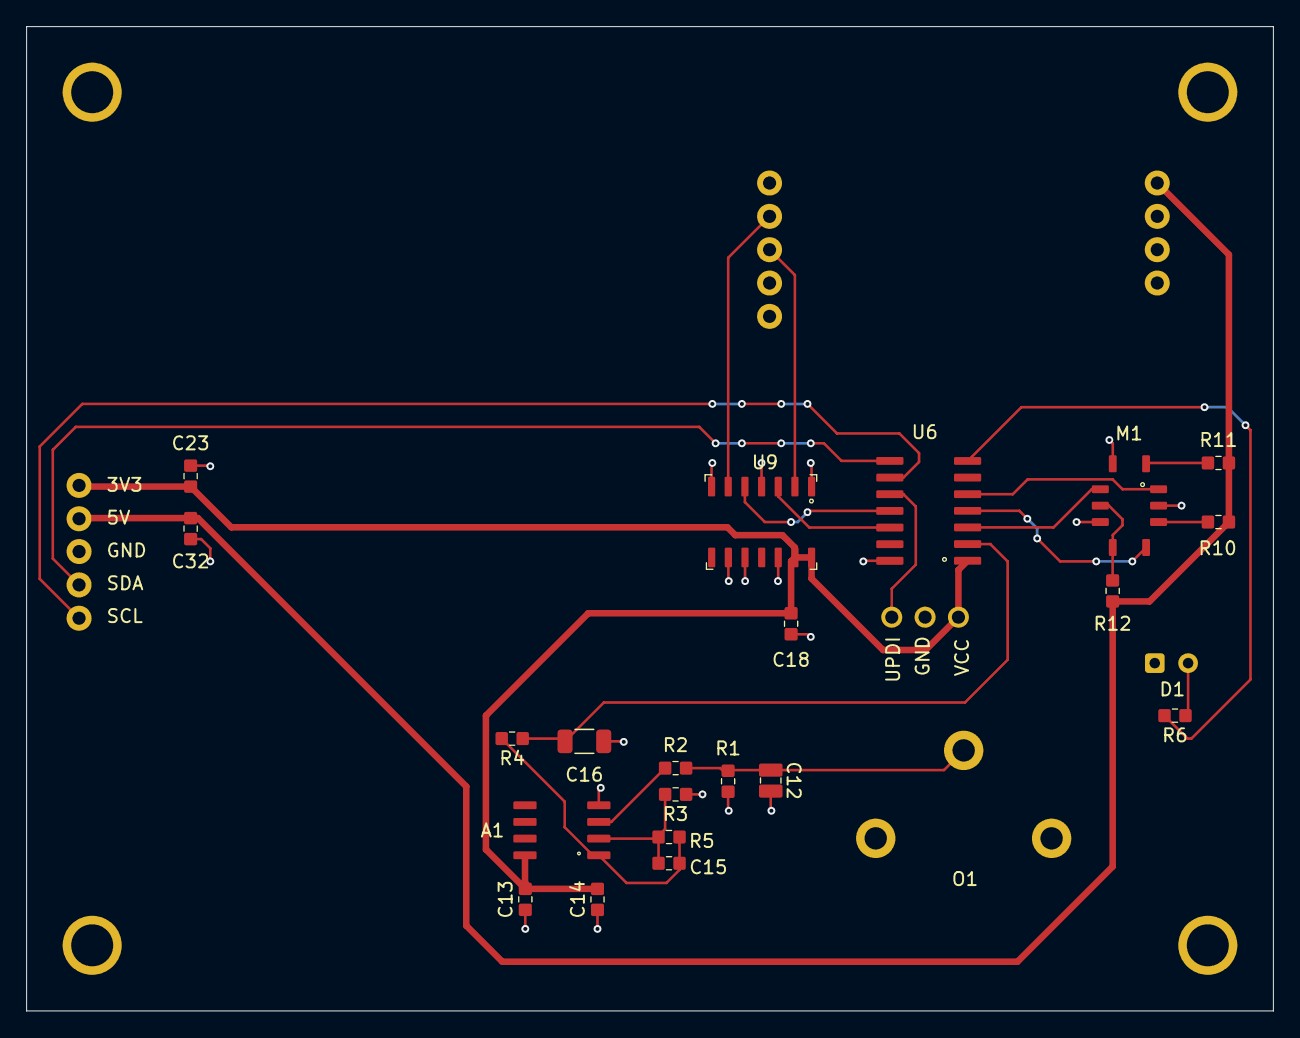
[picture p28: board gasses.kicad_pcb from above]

Board: 2 copper layers, 95.0 x 75.0 mm, 26 parts (0 on the bottom side), 23 nets.

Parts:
A1: AD8552
C12: 4.7uF; C_0805
C13, C14, C15: 10nF; C_0603
C16: 10uF; C_1206
C18, C23, C32: 100nF; C_0603
D1: LED_3mm_THT
G2: Module Connector; GPIO_HEADER
J1: Program Header; ATtiny_Programming_Header
M1: MiCS-6814
O1: AO-03; AO_03
R1, R4: 100R; R_0603
R2, R3: 10K; R_0603
R5: 400K; R_0603
R6: 220; R_0603
R10: 27R; R_0603
R11: 130; R_0603
R12: 820R; R_0603
S5: MH-Z1911A
U6: ATtiny1614
U9: Buffer; SN74LVC125

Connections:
02_A: C16.2, R4.1, U6.2 (PA4)
3V3: A1.8 (+Vs), C13.2, C14.2, C18.1, C23.2, G2.1 (3V3), J1.1 (VCC), U6.1 (VDD), U9.13 (4OE), U9.14 (VCC)
5V: C32.1, G2.2 (5V), R10.2, R11.2, R12.1, S5.9 (VIN)
AT_GAS_RX: U6.12 (PA2), U9.3 (1Y)
AT_GAS_TX: U6.11 (PA1), U9.5 (2A)
CO2_RX: S5.4 (RX), U9.6 (2Y)
CO2_TX: S5.3 (TX), U9.2 (1A)
CO_VAL: M1.8 (H), U6.3 (PA5)
GND: A1.4 (-Vs), C12.2, C13.1, C14.1, C16.1, C18.2, C23.1, C32.2, D1.1 (K), G2.3 (GND), J1.2 (GND), M1.2 (B), M1.6 (F), M1.9 (J), O1.2 (Vsensor-), R1.1, R3.1, S5.8 (GND), U6.14 (GND), U9.1 (1OE), U9.4 (2OE), U9.7 (GND), U9.9 (3A), U9.10 (3OE), U9.12 (4A)
NH3_VAL: M1.4 (D), U6.4 (PA6)
NO2_VAL: M1.1 (A), U6.5 (PA7)
unnamed: A1.3 (+IN_A), R2.2
unnamed: A1.2 (-IN_A), C15.2, R3.2, R5.2
unnamed: A1.1 (OUT_A), C15.1, R4.2, R5.1
unnamed: D1.2 (A), R6.2
unnamed: M1.3 (C), R10.1
unnamed: M1.5 (E), M1.7 (G), R12.2
unnamed: M1.10 (K), R11.1
unnamed: C12.1, O1.1 (Vsensor+), R1.2, R2.1
SCL: G2.5 (SCL), U6.9 (PB0)
SDA: G2.4 (SDA), U6.8 (PB1)
STATUS_LED: R6.1, U6.7 (TOSC2/PB2)
UPDI: J1.3 (UPDI), U6.10 (PA0/RST/UPDI)

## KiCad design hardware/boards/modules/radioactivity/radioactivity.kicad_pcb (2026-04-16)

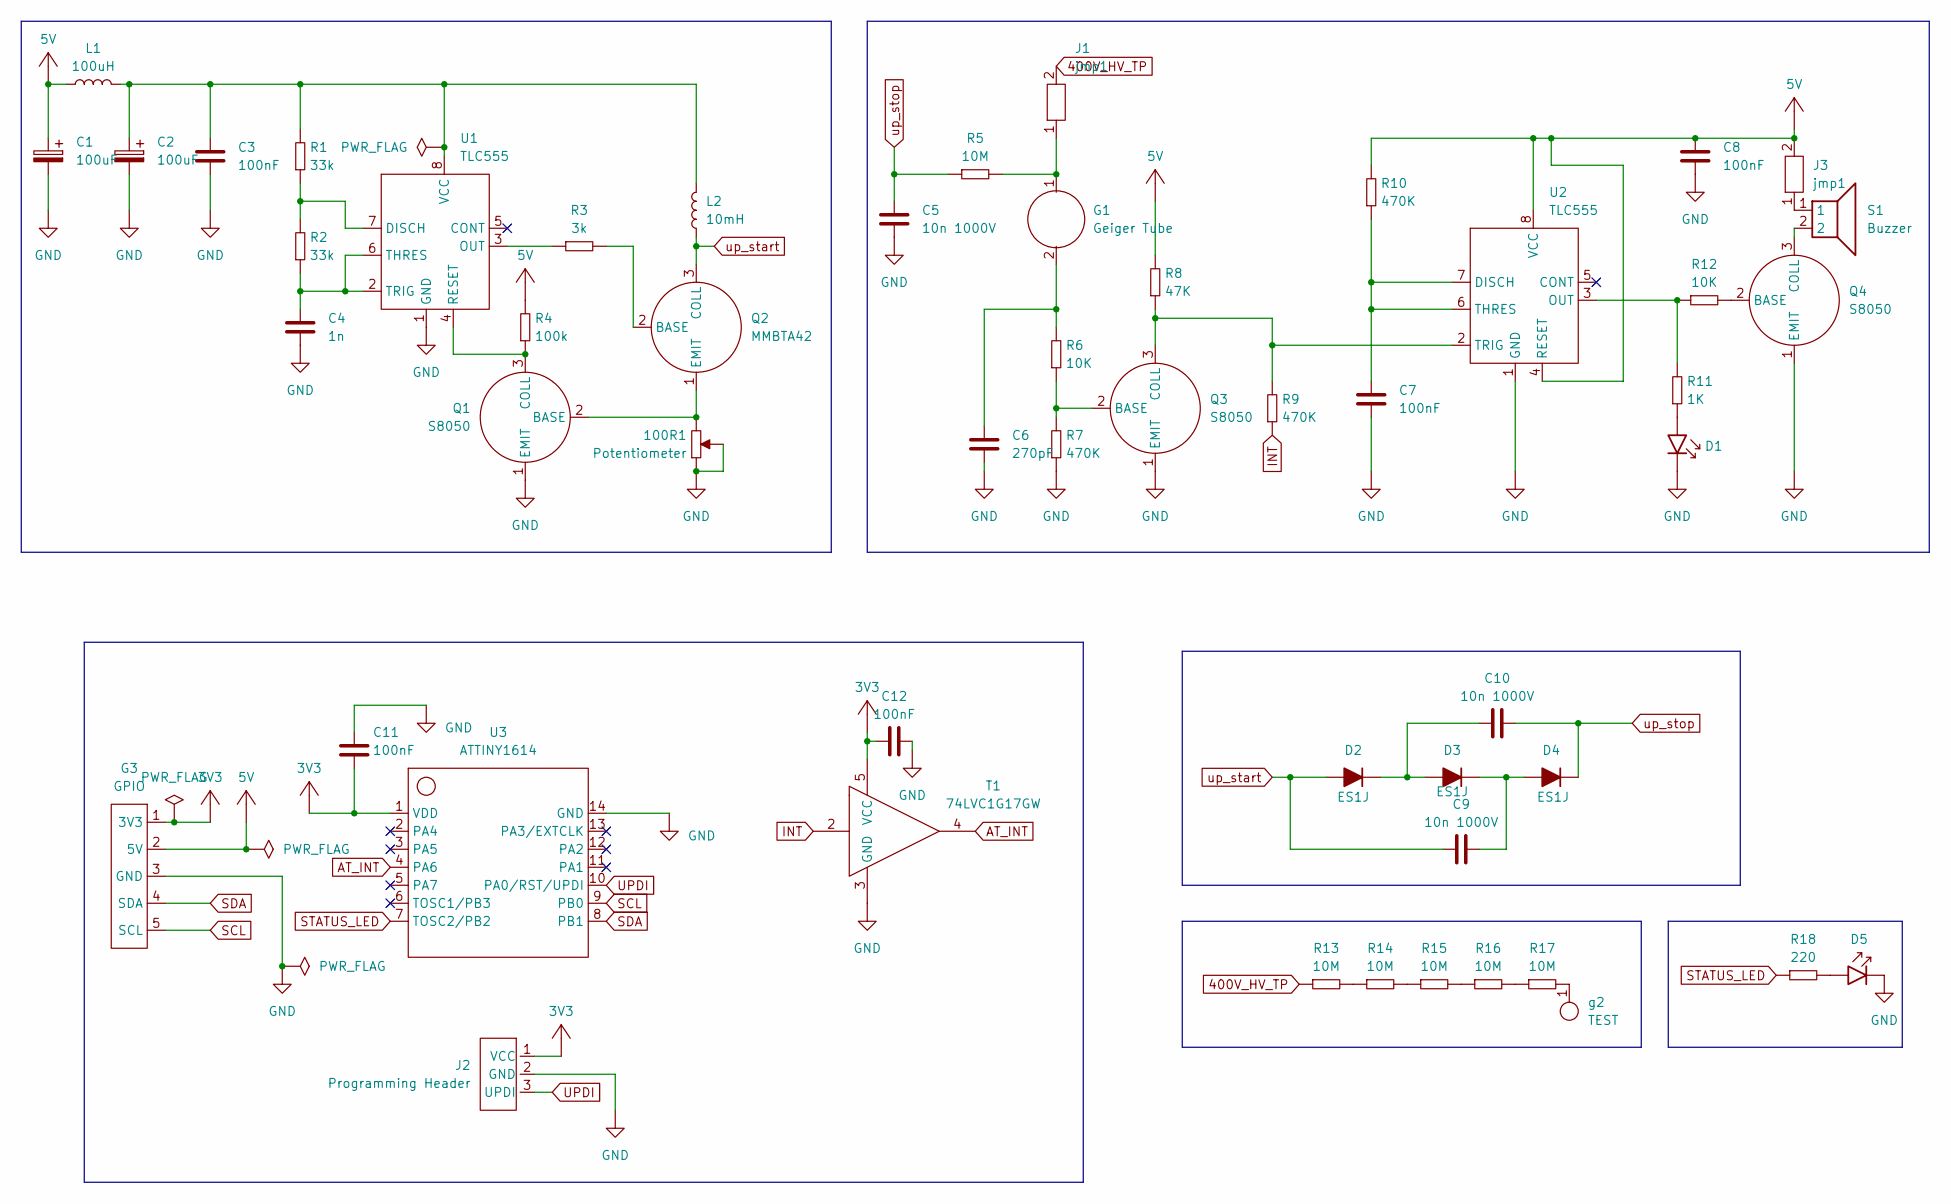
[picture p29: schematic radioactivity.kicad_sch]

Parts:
100R1: Potentiometer; SMD_3P_3.8X3.6
C1, C2: 100uF; C_Elec_SMD_5x5.4
C3, C7, C8, C11, C12: 100nF; C_0603
C4: 1n; C_0603
C5, C9, C10: 10n 1000V; C_1206
C6: 270pF; C_0603
D1: LED_0603
D2, D3, D4: ES1J; SMA(DO-214AC)
D5: LED_3mm_THT
G1: Geiger Tube; Geiger_Tube_J305
G3: GPIO; GPIO_HEADER
J1, J3: jmp1; Jumper_2
J2: Programming Header; ATtiny_Programming_Header
L1: 100uH; SMD(7.1x6.6)
L2: 10mH; C_0603
Q1, Q3, Q4: S8050; SOT-23
Q2: MMBTA42; SOT-23
R1, R2: 33k; R_0603
R3: 3k; R_0603
R4: 100k; R_0603
R5, R13, R14, R15, R16, R17: 10M; R_0603
R6, R12: 10K; R_0603
R7, R9, R10: 470K; R_0603
R8: 47K; R_0603
R11: 1K; R_0603
R18: 220; R_0603
S1: Buzzer; buzzer_8.5x8.5
T1: 74LVC1G17GW; SOT353
U1, U2: TLC555; SOIC-8
U3: ATTINY1614; ATtiny1614
g2: TEST; gpio_1

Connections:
400V_HV_TP: J1.2, R13.1
AT_INT: T1.4, U3.4 (PA6)
INT: R9.1, T1.2
unnamed: C6.2, G1.2, R6.2
unnamed: D1.2 (A), R11.1
unnamed: C10.1, D2.1 (K), D3.2 (A)
unnamed: C9.2, D3.1 (K), D4.2 (A)
unnamed: D5.2 (A), R18.2
unnamed: G1.1, J1.1, R5.2
unnamed: J3.1, S1.1
unnamed: 100R1.3, Q1.2 (BASE), Q2.1 (EMIT)
unnamed: Q1.3 (COLL), R4.1, U1.4 (RESET)
unnamed: Q2.2 (BASE), R3.2
unnamed: Q3.2 (BASE), R6.1, R7.2
unnamed: Q3.3 (COLL), R8.1, R9.2, U2.2 (TRIG)
unnamed: Q4.2 (BASE), R12.2
unnamed: Q4.3 (COLL), S1.2
unnamed: R13.2, R14.1
unnamed: R14.2, R15.1
unnamed: R15.2, R16.1
unnamed: R16.2, R17.1
unnamed: R17.2, g2.1
unnamed: R1.1, R2.2, U1.7 (DISCH)
unnamed: R3.1, U1.3 (OUT)
unnamed: C4.2, R2.1, U1.2 (TRIG), U1.6 (THRES)
unnamed: C7.2, R10.1, U2.6 (THRES), U2.7 (DISCH)
unnamed: R11.2, R12.1, U2.3 (OUT)
SCL: G3.5 (SCL), U3.9 (PB0)
SDA: G3.4 (SDA), U3.8 (PB1)
STATUS_LED: R18.1, U3.7 (TOSC2/PB2)
UPDI: J2.3 (UPDI), U3.10 (PA0/RST/UPDI)
up_start: C9.1, D2.2 (A), L2.1, Q2.3 (COLL)
up_stop: C5.2, C10.2, D4.1 (K), R5.1

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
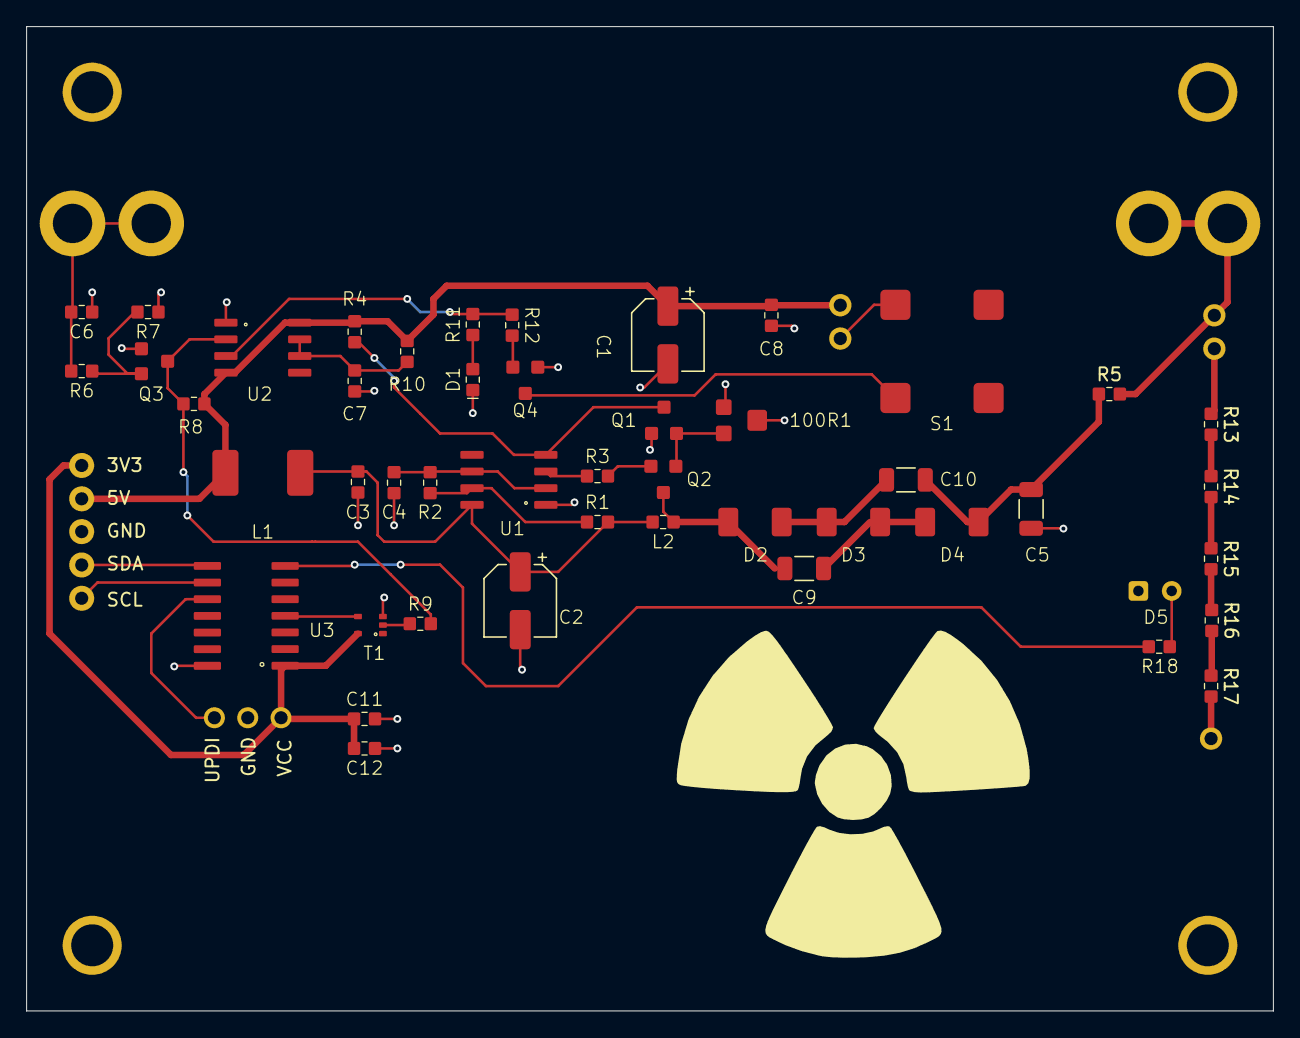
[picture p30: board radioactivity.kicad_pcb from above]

Board: 2 copper layers, 95.0 x 75.0 mm, 53 parts (0 on the bottom side), 37 nets.

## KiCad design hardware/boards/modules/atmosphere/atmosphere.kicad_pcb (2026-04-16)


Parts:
C19, C20, C21, C22, C31: 100nF; C_0603
D1: LED_3mm_THT
G1: GPIO_HEADER
J4: ATtiny_Programming_Header
R1: 220; R_0603
S3: BME280
S4: SDS011
U7: ATtiny1614
U8: buffer; SN74LVC125

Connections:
3V3: C19.1, C20.2, C21.2, C22.2, G1.1 (3V3), J4.1 (VCC), S3.2 (CSB), S3.6 (VDDIO), S3.8 (VDD), U7.1 (VDD), U8.14 (VCC)
5V: C31.2, G1.2 (5V), S4.3 (5V)
AT_CLIM_RX: U7.12 (PA2), U8.3 (1Y)
AT_CLIM_TX: U7.11 (PA1), U8.5 (2A)
GND: C19.2, C20.1, C21.1, C22.1, C31.1, D1.1 (K), G1.3 (GND), J4.2 (GND), S3.1 (GND), S3.5 (SDO), S3.7 (GND), S4.5 (GND), U7.14 (GND), U8.1 (1OE), U8.4 (2OE), U8.7 (GND)
unnamed: D1.2 (A), R1.2
PM_RX: S4.6 (RX), U8.6 (2Y)
PM_TX: S4.7 (TX), U8.2 (1A)
SCL: G1.5 (SCL), S3.4 (SCK), U7.9 (PB0)
SDA: G1.4 (SDA), S3.3 (SDI), U7.8 (PB1)
STATUS_LED: R1.1, U7.7 (TOSC2/PB2)
UPDI: J4.3 (UPDI), U7.10 (PA0/RST/UPDI)


Board: 2 copper layers, 95.0 x 75.0 mm, 13 parts (0 on the bottom side), 12 nets.

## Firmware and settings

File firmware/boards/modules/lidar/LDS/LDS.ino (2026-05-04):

#include "src/LDS_YDLIDAR_X2_X2L.h"
#include <ESP32Servo.h>
#include <Wire.h>

#define SERVO_A_PIN 25
#define SERVO_B_PIN 26
#define SERVO_DEG_REEL_MIN 45
#define SERVO_DEG_REEL_MAX 135
#define SERVO_MOUV_DEG_1 1
#define SERVO_MOUV_DEG_2 5

#define LIDAR_EN_PIN 2
#define LIDAR_PWM_PIN 4
#define LIDAR_RX_PIN 16
#define LIDAR_PWM_FREQ 10000
#define LIDAR_PWM_BITS 11
#define LIDAR_PWM_CHANNEL 2

#define I2C_ADDR 0x0C
#define I2C_CMD_SERVO_A_L1 0x10
#define I2C_CMD_SERVO_A_L2 0x11
#define I2C_CMD_SERVO_A_R1 0x12
#define I2C_CMD_SERVO_A_R2 0x13
#define I2C_CMD_SERVO_B_L1 0x14
#define I2C_CMD_SERVO_B_L2 0x15
#define I2C_CMD_SERVO_B_R1 0x16
#define I2C_CMD_SERVO_B_R2 0x17
#define I2C_CMD_LIDAR_ON 0x20
#define I2C_CMD_LIDAR_OFF 0x21

Servo servoA; uint8_t _servo_a_pos = 90;
Servo servoB; uint8_t _servo_b_pos = 90;

void servo_update_pos(void)
{
	if (_servo_a_pos < SERVO_DEG_REEL_MIN) _servo_a_pos = SERVO_DEG_REEL_MIN;
	if (_servo_a_pos > SERVO_DEG_REEL_MAX) _servo_a_pos = SERVO_DEG_REEL_MAX;
	if (_servo_b_pos < SERVO_DEG_REEL_MIN) _servo_b_pos = SERVO_DEG_REEL_MIN;
	if (_servo_b_pos > SERVO_DEG_REEL_MAX) _servo_b_pos = SERVO_DEG_REEL_MAX;
	servoA.write(_servo_a_pos);
	servoB.write(_servo_b_pos);
}

void onReceive(int len) {
	while (Wire.available()) {
		uint8_t cmd = Wire.read();

		switch (cmd) {
			// --- Servo A ---
			case I2C_CMD_SERVO_A_L1: _servo_a_pos -= SERVO_MOUV_DEG_1; servo_update_pos(); break;
			case I2C_CMD_SERVO_A_L2: _servo_a_pos -= SERVO_MOUV_DEG_2; servo_update_pos(); break;
			case I2C_CMD_SERVO_A_R1: _servo_a_pos += SERVO_MOUV_DEG_1; servo_update_pos(); break;
			case I2C_CMD_SERVO_A_R2: _servo_a_pos += SERVO_MOUV_DEG_2; servo_update_pos(); break;
			// --- Servo B ---
			case I2C_CMD_SERVO_B_L1: _servo_b_pos -= SERVO_MOUV_DEG_1; servo_update_pos(); break;
			case I2C_CMD_SERVO_B_L2: _servo_b_pos -= SERVO_MOUV_DEG_2; servo_update_pos(); break;
			case I2C_CMD_SERVO_B_R1: _servo_b_pos += SERVO_MOUV_DEG_1; servo_update_pos(); break;
			case I2C_CMD_SERVO_B_R2: _servo_b_pos += SERVO_MOUV_DEG_2; servo_update_pos(); break;
			// --- Lidar ---
			case I2C_CMD_LIDAR_ON: digitalWrite(LIDAR_EN_PIN, HIGH); break;
			case I2C_CMD_LIDAR_OFF: digitalWrite(LIDAR_EN_PIN, LOW); break;
			default: break;
		}
	}
}

HardwareSerial LidarSerial(1);
LDS_YDLIDAR_X2_X2L lidar;

uint16_t tab_dist_deg_cm[360]; // motor is 0°, CW

void onRequest() {
	uint8_t buf[8];
	buf[0] = tab_dist_deg_cm[0] >> 8;
	buf[1] = tab_dist_deg_cm[0] & 0xFF;
	buf[2] = tab_dist_deg_cm[90] >> 8;
	buf[3] = tab_dist_deg_cm[90] & 0xFF;
	buf[4] = tab_dist_deg_cm[180] >> 8;
	buf[5] = tab_dist_deg_cm[180] & 0xFF;
	buf[6] = tab_dist_deg_cm[270] >> 8;
	buf[7] = tab_dist_deg_cm[270] & 0xFF;
	Wire.write(buf, 8);
}

void setup() {
	for (int i = 0; i < 360; i++) tab_dist_deg_cm[i] = 0;
	//Serial.begin(115200);

	pinMode(LIDAR_EN_PIN, OUTPUT); digitalWrite(LIDAR_EN_PIN, LOW);
	LidarSerial.begin(115200, SERIAL_8N1, LIDAR_RX_PIN);
	lidar.setScanPointCallback(lidar_scan_point_callback);
	lidar.setPacketCallback(lidar_packet_callback);
	lidar.setSerialWriteCallback(lidar_serial_write_callback);
	lidar.setSerialReadCallback(lidar_serial_read_callback);
	lidar.setMotorPinCallback(lidar_motor_pin_callback);
	lidar.init();
	lidar.start();

	servoA.attach(SERVO_A_PIN, 500, 2500); servoA.write(_servo_a_pos);
	servoB.attach(SERVO_B_PIN, 500, 2500); servoB.write(_servo_b_pos);

	Wire.begin(I2C_ADDR);
	Wire.onReceive(onReceive);
	Wire.onRequest(onRequest);
}

int lidar_serial_read_callback() { return LidarSerial.read(); }

size_t lidar_serial_write_callback(const uint8_t * buffer, size_t length) { return LidarSerial.write(buffer, length); }

void lidar_scan_point_callback(float angle_deg, float distance_mm, float quality, bool scan_completed) {
	tab_dist_deg_cm[(int)angle_deg] = (int)(distance_mm / 10);
}

void lidar_motor_pin_callback(float value, LDS::lds_pin_t lidar_pin) {
	if (value <= (float)LDS::DIR_INPUT)
		pinMode(LIDAR_PWM_PIN, (value == (float)LDS::DIR_INPUT) ? INPUT : OUTPUT);
	else
		digitalWrite(LIDAR_PWM_PIN, (value == (float)LDS::VALUE_HIGH) ? HIGH : LOW);
}

void lidar_packet_callback(uint8_t * packet, uint16_t length, bool scan_completed) { return; }

void loop()
{
	lidar.loop();
	/* if (Serial.available()) {
		for (int i = 0; i < 360; i++) {
			Serial.print(i);
			Serial.print("°: ");
			Serial.print(tab_dist_deg_cm[i]);
			Serial.print("cm | ");
		}
		Serial.println();
	} */
}

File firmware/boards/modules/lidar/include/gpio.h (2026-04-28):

#ifndef GPIO_H
# define GPIO_H

typedef struct {
	volatile uint8_t	*ddr;
	volatile uint8_t	*port;
	volatile uint8_t	*pin;
	uint8_t				bit;
}					gpio_t;

# define _PA0 ((gpio_t){&DDRA, &PORTA, &PINA, PA0})
# define _PA1 ((gpio_t){&DDRA, &PORTA, &PINA, PA1})
# define _PA2 ((gpio_t){&DDRA, &PORTA, &PINA, PA2})
# define _PA3 ((gpio_t){&DDRA, &PORTA, &PINA, PA3})
# define _PA4 ((gpio_t){&DDRA, &PORTA, &PINA, PA4})
# define _PA5 ((gpio_t){&DDRA, &PORTA, &PINA, PA5})
# define _PA6 ((gpio_t){&DDRA, &PORTA, &PINA, PA6})
# define _PA7 ((gpio_t){&DDRA, &PORTA, &PINA, PA7})

# define _PB0 ((gpio_t){&DDRB, &PORTB, &PINB, PB0})
# define _PB1 ((gpio_t){&DDRB, &PORTB, &PINB, PB1})
# define _PB2 ((gpio_t){&DDRB, &PORTB, &PINB, PB2})
# define _PB3 ((gpio_t){&DDRB, &PORTB, &PINB, PB3})
# define _PB4 ((gpio_t){&DDRB, &PORTB, &PINB, PB4})
# define _PB5 ((gpio_t){&DDRB, &PORTB, &PINB, PB5})
# define _PB6 ((gpio_t){&DDRB, &PORTB, &PINB, PB6})
# define _PB7 ((gpio_t){&DDRB, &PORTB, &PINB, PB7})

# define _PC0 ((gpio_t){&DDRC, &PORTC, &PINC, PC0})
# define _PC1 ((gpio_t){&DDRC, &PORTC, &PINC, PC1})
# define _PC2 ((gpio_t){&DDRC, &PORTC, &PINC, PC2})
# define _PC3 ((gpio_t){&DDRC, &PORTC, &PINC, PC3})
# define _PC4 ((gpio_t){&DDRC, &PORTC, &PINC, PC4})
# define _PC5 ((gpio_t){&DDRC, &PORTC, &PINC, PC5})
# define _PC6 ((gpio_t){&DDRC, &PORTC, &PINC, PC6})
# define _PC7 ((gpio_t){&DDRC, &PORTC, &PINC, PC7})

# define _PD0 ((gpio_t){&DDRD, &PORTD, &PIND, PD0})
# define _PD1 ((gpio_t){&DDRD, &PORTD, &PIND, PD1})
# define _PD2 ((gpio_t){&DDRD, &PORTD, &PIND, PD2})
# define _PD3 ((gpio_t){&DDRD, &PORTD, &PIND, PD3})
# define _PD4 ((gpio_t){&DDRD, &PORTD, &PIND, PD4})
# define _PD5 ((gpio_t){&DDRD, &PORTD, &PIND, PD5})
# define _PD6 ((gpio_t){&DDRD, &PORTD, &PIND, PD6})
# define _PD7 ((gpio_t){&DDRD, &PORTD, &PIND, PD7})

# define _PE0 ((gpio_t){&DDRE, &PORTE, &PINE, PE0})
# define _PE1 ((gpio_t){&DDRE, &PORTE, &PINE, PE1})
# define _PE2 ((gpio_t){&DDRE, &PORTE, &PINE, PE2})
# define _PE3 ((gpio_t){&DDRE, &PORTE, &PINE, PE3})
# define _PE4 ((gpio_t){&DDRE, &PORTE, &PINE, PE4})
# define _PE5 ((gpio_t){&DDRE, &PORTE, &PINE, PE5})
# define _PE6 ((gpio_t){&DDRE, &PORTE, &PINE, PE6})
# define _PE7 ((gpio_t){&DDRE, &PORTE, &PINE, PE7})

# define _PF0 ((gpio_t){&DDRF, &PORTF, &PINF, PF0})
# define _PF1 ((gpio_t){&DDRF, &PORTF, &PINF, PF1})
# define _PF2 ((gpio_t){&DDRF, &PORTF, &PINF, PF2})
# define _PF3 ((gpio_t){&DDRF, &PORTF, &PINF, PF3})
# define _PF4 ((gpio_t){&DDRF, &PORTF, &PINF, PF4})
# define _PF5 ((gpio_t){&DDRF, &PORTF, &PINF, PF5})
# define _PF6 ((gpio_t){&DDRF, &PORTF, &PINF, PF6})
# define _PF7 ((gpio_t){&DDRF, &PORTF, &PINF, PF7})

# define _PG0 ((gpio_t){&DDRG, &PORTG, &PING, PG0})
# define _PG1 ((gpio_t){&DDRG, &PORTG, &PING, PG1})
# define _PG2 ((gpio_t){&DDRG, &PORTG, &PING, PG2})
# define _PG3 ((gpio_t){&DDRG, &PORTG, &PING, PG3})
# define _PG4 ((gpio_t){&DDRG, &PORTG, &PING, PG4})
# define _PG5 ((gpio_t){&DDRG, &PORTG, &PING, PG5})
# define _PG6 ((gpio_t){&DDRG, &PORTG, &PING, PG6})
# define _PG7 ((gpio_t){&DDRG, &PORTG, &PING, PG7})

#endif

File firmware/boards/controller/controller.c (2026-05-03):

#include <avr/interrupt.h>

#include "controller.h"

#define _CONTROLLER_ADC_MAX 1023U

// Calibration of joystick
#define _ADC_CONVERT_LX(x) ((((int)x - 505) / 19) * 10)
#define _ADC_CONVERT_LY(x) ((((int)x - 518) / 20) * 10)
#define _ADC_CONVERT_RX(x) (((504 - (int)x) / 19) * 10)
#define _ADC_CONVERT_RY(x) (((538 - (int)x) / 20) * 10)

#define _CONTROLLER_MODE_COUNT 5
#define _CONTROLLER_MASK_MODE 0x0F           /**< Mask of display */
#define _CONTROLLER_MODE_ATM PACKET_ID_ATM   /**< Display atmospheric data */
#define _CONTROLLER_MODE_GAS PACKET_ID_GAS   /**< Display gas data */
#define _CONTROLLER_MODE_MAP PACKET_ID_LIDAR /**< Display map */
#define _CONTROLLER_MODE_GMC PACKET_ID_GMC   /**< Display radioactivity data */

#define _CONTROLLER_MODE_RX 0x10    /**< RX mode */
#define _CONTROLLER_MODE_TX 0x20    /**< TX mode */
#define _CONTROLLER_MASK_RADIO 0xF0 /**< Mask of Controller transmission mode */

#define _CONTROLLER_RX_DELAY 8000U /**< Delay for reception */

#define _DISPLAY_W 8U
#define _DISPLAY_H 8U
#define _DISPLAY_MODULE_OFFSET 12

/** @brief Maximum signal strength */
#define _RADIO_SIGNAL_MAX 0x10

controller_t g_controller;
packet_t g_packet;
packet_t g_packet_tx;

volatile byte_t g_ctrl_mode = 1;      /**< Controller mode flags */
volatile byte_t g_module_curr = 1;    /**< Current display mode */
volatile byte_t g_module_en;          /**< Current enabled modules */
volatile byte_t g_radio_status;       /**< Radio strength */
volatile byte_t g_save_enabled = 0;   /**< SD save enabled flag */
volatile bool_t g_save_toggle = FALSE; /**< Pending save toggle from ISR */

/**
 * @brief Decrease signal strength count,
 * when it reaches to 0, the connection is lost
 */
static inline void _CONTROLLER_disconnect(void);

/**
 * @brief Increase signal strength count
 */
static inline void _CONTROLLER_connect(void);

/**
 * @brief Reset signal strength count
 */
static inline void _CONTROLLER_reset_connection(void);

/**
 * @brief Display layout
 */
static void _CONTROLLER_display_layout(const char *label);

/**
 * @brief Display available modules
 */
static void _CONTROLLER_display_module(void);

static void _CONTROLLER_display_save(bool_t save);

/**
 * @brief Check communication mode
 */
static void _CONTROLLER_set_radio_mode(void);

/**
 * @brief When multiple modules are connected, switch between them
 */
static void _CONTROLLER_switch_display(void);

//------------------------------------------------------------------------------
// setup
//------------------------------------------------------------------------------
void setup(void)
{
#ifdef VEMAR_DEBUG_ENABLED
    SERIAL_init();
#endif

    CONTROLLER_DEBUG(str, "start setup\r\n");
    CONTROLLER_init();
    RADIO_init(PIN_RADIO_CE, PIN_RADIO_CSN);
    TFT_init(PIN_TFT_CS, PIN_TFT_DC, PIN_TFT_RST);
    TFT_set_mode(TFT_LANDSCAPE, TFT_INVERTED, TFT_INVERTED);
    TFT_setup_text(TFT_TEXT_S, 1, RGB16_WHITE, RGB16_BLACK);
    CONTROLLER_interrupt();
    CONTROLLER_display_menu();
    _CONTROLLER_reset_connection();
    _CONTROLLER_set_radio_mode();
    CONTROLLER_DEBUG(str, "end setup\r\n");
}

//------------------------------------------------------------------------------
// main loop
//------------------------------------------------------------------------------
void loop(void)
{
    if (g_save_toggle)
    {
        g_save_toggle = FALSE;
        g_save_enabled ^= 1;
        _CONTROLLER_display_save(g_save_enabled);
    }
    if (BIT_is_set(g_ctrl_mode, _CONTROLLER_MODE_RX))
    {
        CONTROLLER_read();
    }
    if (BIT_is_set(g_ctrl_mode, _CONTROLLER_MODE_TX))
    {
        CONTROLLER_write();
    }
    CONTROLLER_update_connection();
}

//------------------------------------------------------------------------------
// CONTROLLER_init
//------------------------------------------------------------------------------
void CONTROLLER_init(void)
{
    g_controller.tgl.up = BUTTON_new(PIN_TOGGLE_UP, BUTTON_ONHOLD);
    g_controller.tgl.down = BUTTON_new(PIN_TOGGLE_DOWN, BUTTON_ONHOLD);
    g_controller.btn1 = BUTTON_new(PIN_BUTTON1, BUTTON_ONPRESS);
    g_controller.btn2 = BUTTON_new(PIN_BUTTON2, BUTTON_ONPRESS);
    g_controller.pot = ANALOG_new(PIN_POTENTIOMETER);
    g_controller.jright = JOYSTICK_new(PIN_JOY_RX, PIN_JOY_RY, PIN_JOY_RB);
    g_controller.jleft = JOYSTICK_new(PIN_JOY_LX, PIN_JOY_LY, PIN_JOY_LB);
    g_controller.led = LED_new(PIN_LED);
}

void CONTROLLER_interrupt(void)
{
    BIT_set(PCICR, (BIT(PCIE1) | BIT(PCIE2)));      // enable interrupt (Port C & D)
    BIT_set(PCMSK1, (BIT(PCINT8) | BIT(PCINT9)));   // enable PC0 and PC1
    BIT_set(PCMSK2, (BIT(PCINT19) | BIT(PCINT20))); // enable PD3 and PD4
    sei();
}

//------------------------------------------------------------------------------
// CONTROLLER_display_data
//------------------------------------------------------------------------------
void CONTROLLER_display_atmosphere(void)
{
    if (_CONTROLLER_MODE_ATM != BIT_read(g_ctrl_mode, _CONTROLLER_MASK_MODE))
    {
        TFT_fill_screen(RGB16_BLACK);
        _CONTROLLER_display_layout("MODULE: Atmosphere");
        TFT_print_str(COL1, ROW1, "Temperature: ");
        TFT_print_str(COL3, ROW1, "C");
        TFT_print_str(COL1, ROW2, "Humidity   : ");
        TFT_print_str(COL3, ROW2, "%RH");
        TFT_print_str(COL1, ROW3, "Pressure   : ");
        TFT_print_str(COL3, ROW3, "hPa");
        TFT_print_str(COL1, ROW4, "PM2.5      : ");
        TFT_print_str(COL3, ROW4, "ug/m3");
        TFT_print_str(COL1, ROW5, "PM10       : ");
        TFT_print_str(COL3, ROW5, "ug/m3");
        BIT_write(g_ctrl_mode, _CONTROLLER_MODE_ATM, _CONTROLLER_MASK_MODE);
    }
}

void CONTROLLER_display_gas(void)
{
    if (_CONTROLLER_MODE_GAS != BIT_read(g_ctrl_mode, _CONTROLLER_MASK_MODE))
    {
        TFT_fill_screen(RGB16_BLACK);
        _CONTROLLER_display_layout("MODULE: Gas");
        TFT_print_str(COL1, ROW1, "CO2        : ");
        TFT_print_str(COL3, ROW1, "ppm");
        TFT_print_str(COL1, ROW2, "CO         : ");
        TFT_print_str(COL3, ROW2, "(raw ADC)");
        TFT_print_str(COL1, ROW3, "NH3        : ");
        TFT_print_str(COL3, ROW3, "(raw ADC)");
        TFT_print_str(COL1, ROW4, "NO2        : ");
        TFT_print_str(COL3, ROW4, "(raw ADC)");
        TFT_print_str(COL1, ROW5, "O2         : ");
        TFT_print_str(COL3, ROW5, "(raw ADC)");
        BIT_write(g_ctrl_mode, _CONTROLLER_MODE_GAS, _CONTROLLER_MASK_MODE);
    }
}
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

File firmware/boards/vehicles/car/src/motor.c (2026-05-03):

#include "motor.h"

static void _motor_left_config_pwm(void)
{
	//SET_MSK(TCCR0A, MSK(WGM01) | MSK(WGM00) | MSK(COM0A1) | MSK(COM0B1));  // Fast PWM, non-inverting
	SET_MSK(TCCR0A, MSK(WGM01) | MSK(WGM00));  // Fast PWM, non-inverting, pin disconnected
	SET_MSK(TCCR0B, MSK(CS01));  // prescaler = 8
}

static void _motor_right_config_pwm(void)
{
	//SET_MSK(TCCR1A, MSK(WGM10) | MSK(COM1A1) | MSK(COM1B1));  // Mode 5 (8-bit fast PWM), non-inverting
	SET_MSK(TCCR1A, MSK(WGM10));  // Mode 5 (8-bit fast PWM), non-inverting, pin disconnected
	SET_MSK(TCCR1B, MSK(WGM12) | MSK(CS11));  // prescaler = 8
}

static void _motor_left_disconnect_pwm_cw(void) { CLEAR_MSK(TCCR0A, MSK(COM0B1)); }
static void _motor_left_disconnect_pwm_ccw(void) { CLEAR_MSK(TCCR0A, MSK(COM0A1)); }
static void _motor_right_disconnect_pwm_cw(void) { CLEAR_MSK(TCCR1A, MSK(COM1A1)); }
static void _motor_right_disconnect_pwm_ccw(void) { CLEAR_MSK(TCCR1A, MSK(COM1B1)); }
static void _motor_left_connect_pwm_cw(void) { SET_MSK(TCCR0A, MSK(COM0B1)); }
static void _motor_left_connect_pwm_ccw(void) { SET_MSK(TCCR0A, MSK(COM0A1)); }
static void _motor_right_connect_pwm_cw(void) { SET_MSK(TCCR1A, MSK(COM1A1)); }
static void _motor_right_connect_pwm_ccw(void) { SET_MSK(TCCR1A, MSK(COM1B1)); }

static void _motor_left_disable_cw(void) { _motor_left_disconnect_pwm_cw(); GPIO_CLEAR(MOTOR_LEFT_PWM_CW); GPIO_CLEAR(MOTOR_LEFT_EN_CW); }
static void _motor_left_disable_ccw(void) { _motor_left_disconnect_pwm_ccw(); GPIO_CLEAR(MOTOR_LEFT_PWM_CCW); GPIO_CLEAR(MOTOR_LEFT_EN_CCW); }
static void _motor_right_disable_cw(void) { _motor_right_disconnect_pwm_cw(); GPIO_CLEAR(MOTOR_RIGHT_PWM_CW); GPIO_CLEAR(MOTOR_RIGHT_EN_CW); }
static void _motor_right_disable_ccw(void) { _motor_right_disconnect_pwm_ccw(); GPIO_CLEAR(MOTOR_RIGHT_PWM_CCW); GPIO_CLEAR(MOTOR_RIGHT_EN_CCW); }
static void _motor_left_enable_cw(void) { _motor_left_disable_ccw(); _delay_us(DEAD_TIME_US); _motor_left_connect_pwm_cw(); GPIO_SET(MOTOR_LEFT_EN_CW); }
static void _motor_left_enable_ccw(void) { _motor_left_disable_cw(); _delay_us(DEAD_TIME_US); _motor_left_connect_pwm_ccw(); GPIO_SET(MOTOR_LEFT_EN_CCW); }
static void _motor_right_enable_cw(void) { _motor_right_disable_ccw(); _delay_us(DEAD_TIME_US); _motor_right_connect_pwm_cw(); GPIO_SET(MOTOR_RIGHT_EN_CW); }
static void _motor_right_enable_ccw(void) { _motor_right_disable_cw(); _delay_us(DEAD_TIME_US); _motor_right_connect_pwm_ccw(); GPIO_SET(MOTOR_RIGHT_EN_CCW); }

static void _motor_left_set_pwm_cw(uint8_t speed) { OCR0B = speed; }
static void _motor_left_set_pwm_ccw(uint8_t speed) { OCR0A = speed; }
static void _motor_right_set_pwm_cw(uint8_t speed) { OCR1A = speed; }
static void _motor_right_set_pwm_ccw(uint8_t speed) { OCR1B = speed; }

static uint8_t _motor_left_direction = 0;  // 0 = stopped, 1 = cw, 2 = ccw
static uint8_t _motor_right_direction = 0;  // 0 = stopped, 1 = cw, 2 = ccw
static int16_t _motor_left_old_speed = 0;
static int16_t _motor_right_old_speed = 0;

static void _motor_left_ramp_down(void)
{
    uint8_t pwm = (_motor_left_direction == 1) ? (uint8_t)(-_motor_left_old_speed) : (uint8_t)_motor_left_old_speed;
    while (pwm > MOTOR_RAMP_STEP) {
        pwm -= MOTOR_RAMP_STEP;
        if (_motor_left_direction == 1) _motor_left_set_pwm_cw(pwm);
        else _motor_left_set_pwm_ccw(pwm);
        _delay_ms(MOTOR_RAMP_MS);
    }
    if (_motor_left_direction == 1) _motor_left_set_pwm_cw(0);
    else _motor_left_set_pwm_ccw(0);
}

static void _motor_left_ramp_up(uint8_t target)
{
    uint8_t pwm = 0;
    while (pwm + MOTOR_RAMP_STEP < target) {
        pwm += MOTOR_RAMP_STEP;
        if (_motor_left_direction == 1) _motor_left_set_pwm_cw(pwm);
        else _motor_left_set_pwm_ccw(pwm);
        _delay_ms(MOTOR_RAMP_MS);
    }
    if (_motor_left_direction == 1) _motor_left_set_pwm_cw(target);
    else _motor_left_set_pwm_ccw(target);
}

static void _motor_right_ramp_down(void)
{
    uint8_t pwm = (_motor_right_direction == 1) ? (uint8_t)(-_motor_right_old_speed) : (uint8_t)_motor_right_old_speed;
    while (pwm > MOTOR_RAMP_STEP) {
        pwm -= MOTOR_RAMP_STEP;
        if (_motor_right_direction == 1) _motor_right_set_pwm_cw(pwm);
        else _motor_right_set_pwm_ccw(pwm);
        _delay_ms(MOTOR_RAMP_MS);
    }
    if (_motor_right_direction == 1) _motor_right_set_pwm_cw(0);
    else _motor_right_set_pwm_ccw(0);
}

static void _motor_right_ramp_up(uint8_t target)
{
    uint8_t pwm = 0;
    while (pwm + MOTOR_RAMP_STEP < target) {
        pwm += MOTOR_RAMP_STEP;
        if (_motor_right_direction == 1) _motor_right_set_pwm_cw(pwm);
        else _motor_right_set_pwm_ccw(pwm);
        _delay_ms(MOTOR_RAMP_MS);
    }
    if (_motor_right_direction == 1) _motor_right_set_pwm_cw(target);
    else _motor_right_set_pwm_ccw(target);
}

void motor_init(void)
{
	GPIO_OUTPUT(MOTOR_LEFT_EN_CW); _motor_left_disable_cw();
	GPIO_OUTPUT(MOTOR_LEFT_EN_CCW); _motor_left_disable_ccw();
	GPIO_OUTPUT(MOTOR_LEFT_PWM_CW); _motor_left_set_pwm_cw(0);
	GPIO_OUTPUT(MOTOR_LEFT_PWM_CCW); _motor_left_set_pwm_ccw(0);
	_motor_left_config_pwm();

	GPIO_OUTPUT(MOTOR_RIGHT_EN_CW); _motor_right_disable_cw();
	GPIO_OUTPUT(MOTOR_RIGHT_EN_CCW); _motor_right_disable_ccw();
	GPIO_OUTPUT(MOTOR_RIGHT_PWM_CW); _motor_right_set_pwm_cw(0);
	GPIO_OUTPUT(MOTOR_RIGHT_PWM_CCW); _motor_right_set_pwm_ccw(0);
	_motor_right_config_pwm();
}

// -255 to 255 : negative = cw, positive = ccw, 0 = stop
void motor_left_set(int16_t speed)
{
	if (speed < -255 || speed > 255) speed = 0;  // out of range, stop the motor
	if (speed == _motor_left_old_speed) return;  // no change, do nothing
	if (speed == 0)
	{
		_motor_left_disable_cw(); _motor_left_disable_ccw();
		_motor_left_direction = 0; _motor_left_old_speed = 0;
		return;
	}
	if (speed > 0) // ccw
	{
		_motor_left_old_speed = speed;
		if (_motor_left_direction == 1)
		{
			_motor_left_ramp_down();
			_motor_left_set_pwm_ccw(0);
			_motor_left_enable_ccw();
			_motor_left_direction = 2;
			_motor_left_ramp_up((uint8_t)speed);
		}
		else
		{
			_motor_left_set_pwm_ccw((uint8_t)speed);
			if (_motor_left_direction != 2) _motor_left_enable_ccw();
			_motor_left_direction = 2;
		}
		return;
	} // else speed < 0, cw
	_motor_left_old_speed = speed;
	if (_motor_left_direction == 2)
	{
		_motor_left_ramp_down();
		_motor_left_set_pwm_cw(0);
		_motor_left_enable_cw();
		_motor_left_direction = 1;
		_motor_left_ramp_up((uint8_t)(-speed));
	}
	else
	{
		_motor_left_set_pwm_cw((uint8_t)(-speed));
		if (_motor_left_direction != 1) _motor_left_enable_cw();
		_motor_left_direction = 1;
	}
}
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

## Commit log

2025-12-14 adding air sensor schemas
    [SCD40.kicad_sch, SDS011.kicad_sch, air_sensor.kicad_pcb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]
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2026-01-22 update controller schematics
    [controller.kicad_sch]
2026-01-23 controller schematics updated
    [controller.kicad_sch]
2026-01-24 updated schema
    added 5V 3A buck converter
    refined 3v3 LDO
    added symbols for new components
    added text comments for designing the pcb
    [SCD40.kicad_sch, air_sensor.kicad_sch, geiger_module.kicad_sch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]
2026-01-25 vehicle schematic
    [car.kicad_pcb, car.kicad_sch, motors.kicad_sch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]
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2026-01-25 new kicad project for lidar module
    [lidar.kicad_pcb, lidar.kicad_sch]
2026-01-26 fix(controller): tag CE <-> PD6
    [controller.kicad_sch, display.kicad_sch, power.kicad_sch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]
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2026-01-27 feat(pcb): pcb wip
    [controller.kicad_pcb, controller.kicad_sch, display.kicad_sch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]
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2026-01-29 updated power symbol labels, replaced power symbols in schematic with our own custom symbols
    [SCD40.kicad_sch, air_sensor.kicad_sch, geiger_module.kicad_sch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]
2026-01-29 feat(pcb): working pcb design
    [controller.kicad_pcb]
2026-01-29 feat(schematic): cleanup controller
    [controller.kicad_sch, display.kicad_sch, power.kicad_sch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]
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2026-01-30 added pcb for gas and climate modules
    [SCD40.kicad_sch, SDS011.kicad_sch, air_sensor.kicad_pcb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]
2026-01-31 added status LED to gas module
    [air_sensor.kicad_pcb, air_sensor.kicad_sch]
2026-01-31 added status LED to climate module
    [air_sensor.kicad_pcb, air_sensor.kicad_sch]
2026-02-01 lidar schematic
    [accelerometer.kicad_sch, lidar.kicad_sch]
2026-02-01 car schematic
    [car.kicad_sch, power.kicad_sch, transceiver.kicad_sch]
2026-02-01 add BOM
    [Annee_mois_date Demande de depense_(ModuleElec).xlsx]
2026-02-01 added sensor modules to bom
    [Annee_mois_date Demande de depense_(ModuleElec).xlsx]
2026-02-01 added 1206 smd capacitor footprint
    [air_sensor.kicad_pcb, air_sensor.kicad_sch]
2026-02-02 add resistor 330Ohm, capacitor 1nF
    [Annee_mois_date Demande de depense_(ModuleElec).xlsx]
2026-02-02 update controller pcb
    [controller-B_Cu.gbl, controller-B_Mask.gbs, controller-B_Paste.gbp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]
2026-02-02 archive gerber files
    [controller-B_Cu.gbl, controller-B_Mask.gbs, controller-B_Paste.gbp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]
2026-02-02 added all footprints for lidar and car
    [accelerometer.kicad_sch, lidar.kicad_sch, motors.kicad_sch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]
2026-02-02 lidar pcb
    [lidar.kicad_pcb, lidar.kicad_sch]
2026-02-02 car schema updated
    [car.kicad_pcb]
2026-02-03 updated pcb after DRC
    [lidar.kicad_pcb]
2026-02-03 update gerber file
    [controller.kicad_pcb]
2026-02-03 rounded tracks on lidar pcb
    [lidar.kicad_pcb]
2026-02-03 corrected SD card and transceiver on symbol and schema
    [car.kicad_pcb, motors.kicad_sch, sd_card.kicad_sch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]
2026-02-03 added teardrops to lidar pcb
    [lidar.kicad_pcb]
2026-02-03 added gerber files for climate and gas module
    [air_sensor-B_Cu.gbr, air_sensor-B_Mask.gbr, air_sensor-B_Paste.gbr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]
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2026-02-04 pcb for car
    [car.kicad_pcb, car.kicad_sch, motors.kicad_sch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]
2026-02-04 gerber file
    [car-B_Cu.gbl, car-B_Mask.gbs, car-B_Paste.gbp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]
2026-02-04 edited inductor footprint for car and export gerber for lidar
    [car-B_Cu.gbl, car-B_Mask.gbs, car-B_Silkscreen.gbo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]
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2026-02-17 fix issue with transceiver
    [joystick.c]
2026-02-18 REFACTO of all the repo to stick to the planed architecture, STILL NEED to re link everything
    [SCD40.kicad_sch, SDS011.kicad_sch, accelerometer.kicad_sch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]
2026-02-18 REFACTO relinked every kicad projects
    [accelerometer.kicad_sch, atmosphere.kicad_pcb, atmosphere.kicad_sch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]
2026-02-23 started mechanical design for lidar module, bearing and servo f3d files
    [Bearing 608.f3d, Servo Motor SG90.f3d]
2026-02-23 added lidar and motor f3d files
    [Lidar X2L.f3d, Motor 36GP-3530.f3d]
2026-02-25 updated servomotor f3d file with another arm
    [Servo Motor SG90.f3d]
2026-02-25 added lidar f3d file with pivot component
    [Lidar.f3z]
2026-02-25 create architecture for mechanical/export folder with the lidar pivot_frame file
    [pivot_frame.stl]
2026-02-25 updated servomotor model so we can cut support and gain place
    [Lidar.f3z, Servo Motor SG90.f3d, pivot_frame.stl]
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2026-03-20 finished geiger module pcb
    [gasses.kicad_pcb, radioactivity.kicad_pcb, radioactivity.kicad_sch]
2026-03-24 added missing status LED to radioactivity board
    [radioactivity.kicad_pcb, radioactivity.kicad_sch]
2026-03-24 redesigned gas module pcb
    [gasses.kicad_pcb, gasses.kicad_sch]
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2026-03-25 changed nack to ack for empty buffer, reset message index on interrupt
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2026-04-02 new version for pcb controller
    [controller.kicad_pcb, controller.kicad_sch, display.kicad_sch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]
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2026-04-08 add controller gerber file
    [controller.kicad_pcb, controller.kicad_sch]
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2026-04-09 updated main points of the lidar module schematic
    [accelerometer.kicad_sch, lidar.kicad_sch]
2026-04-09 updated main points of the car schematic
    [car.kicad_sch, sd_card.kicad_sch, transceiver.kicad_sch]
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2026-04-13 added teardrops to lidar and car PCB, should be good
    [car.kicad_pcb, lidar.kicad_pcb]
2026-04-13 added production files for lidar and car PCB
    [vemar_car_bom.csv, vemar_car_designators.csv, vemar_car_positions.csv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]
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2026-04-16 fix i2c read
2026-04-16 updated sensor module schematics
    [atmoshere_pcb_bom.csv, atmoshere_pcb_designators.csv, atmoshere_pcb_positions.csv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]
2026-04-16 add kicad transceiver module
    [bom.csv, transceiver.kicad_pcb, transceiver.kicad_sch]
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2026-04-20 corrected buzzer code on car firmware
    [main.c]
2026-04-22 added interactive bom for lidar and car
    [power.kicad_sch]
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2026-05-02 added bme init flag sent to master, slave no longer inits
    [atmosphere.c, atmosphere_slave.c, main.c]
2026-05-02 fixed indices mismatch for gas readings
    [gasses_slave.c]
2026-05-02 fixed sd save implementation
    [main.c]
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2026-05-03 added save toggling to data_save to prevent sd corruption
    [main.c]
2026-05-03 added debounce to save button and updated data save (still not working)
    [controller.c, main.c]
2026-05-03 added motor ramp up and down to prevent current spikes
    [motor.c, motor.h]
2026-05-04 change kicad default to custom
    [accelerometer.kicad_sch, car.kicad_pcb, car.kicad_sch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]
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
